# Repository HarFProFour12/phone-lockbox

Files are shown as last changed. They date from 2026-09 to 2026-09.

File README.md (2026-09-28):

# Tamagotchi Style Phone Lockbox

This is my custom phone lockbox that turns putting your phone away into a little game. All you have to do is put your phone inside, choose for how long you want to lock your phone, and let Byte (the tamagotchi character), keep you company while you stay off your phone.

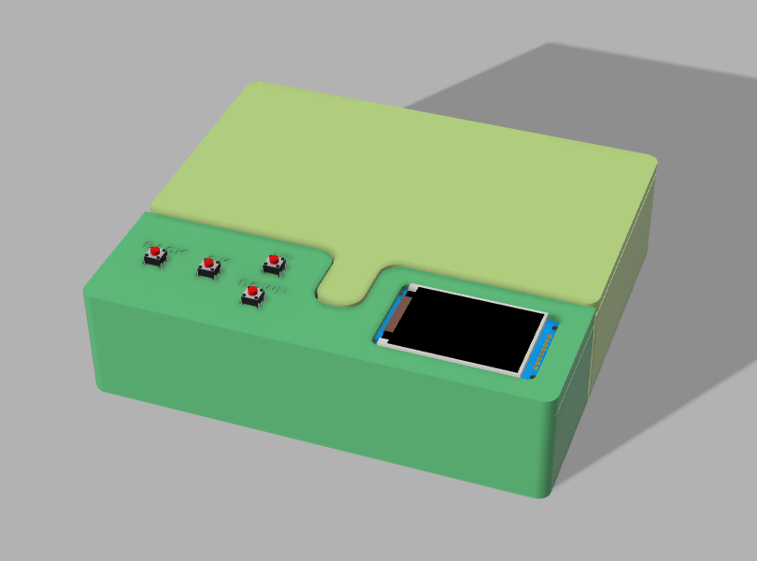
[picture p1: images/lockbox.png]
Phone Lockbox (render)


## Features

* Phone locking for specific amount of time
* Tamagotchi character (Byte)
* Button-controlled UI
* 2" 240×320 SPI TFT IPS screen
* Adjustable lock time
* Adjustable screen brightness
* Battery indicator
* Locking mechanism controlled by solenoid lock

## Interface

The UI is designed with simple menus so it can be navigated using only four buttons (okay, back, up, down). The Home screen uses this layout:

* **Lock Phone**
* **Stats**
* **Settings**
* **About**

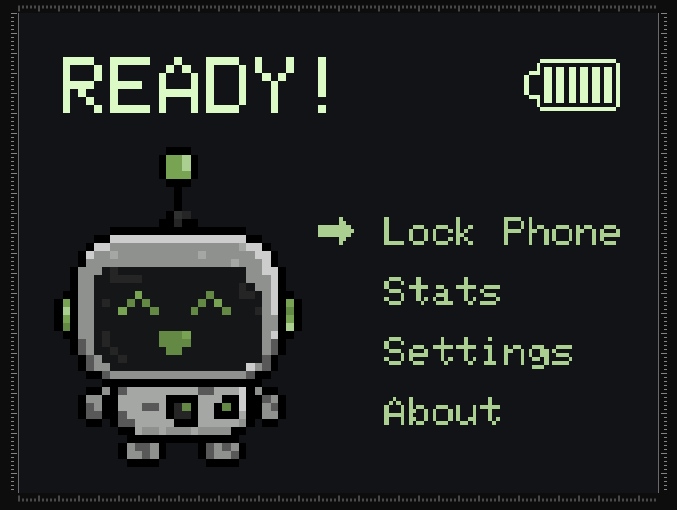
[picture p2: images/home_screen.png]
Home Screen UI


The Settings menu currently contains:

* **Lock Time**
* **Brightness**
* **Sounds**
* **System**

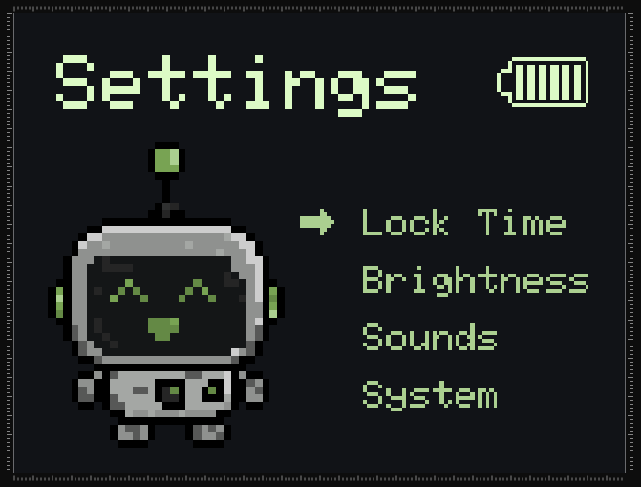
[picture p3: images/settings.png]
Settings Page UI


I've designed seperate sprites for Byte, including idle, happy, celebrating, excited, sad, thinking and sleeping, which change according to your actions.

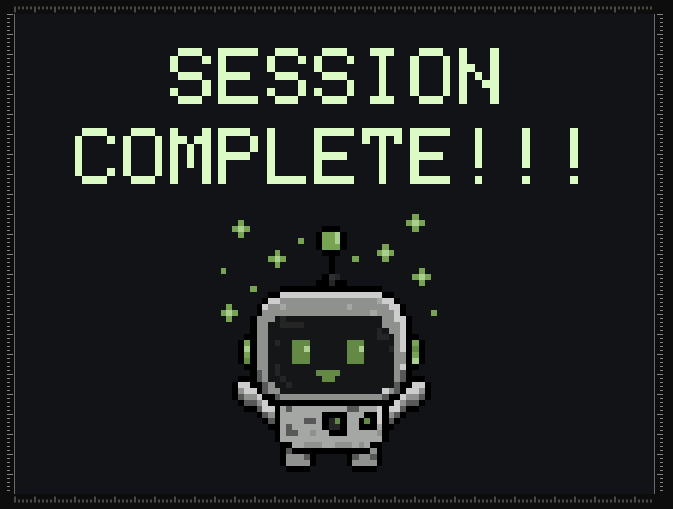
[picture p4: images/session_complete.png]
Session Completed Screen


## How It Works

The lockbox is controlled by an **ESP32-C6-DevKitC-1**. The display show the current screen and whether Byte's happy, sad, excited, etc.. You can control the UI using the 4 physical pushbuttons, which are left from the screen.

When you press "Lock Phone", the lock mechanism starts. First of all, the lipo battrey's current passed through a step=up converter and then activates the solenoid, which unlocks the box. From that time you have 5 seconds to put your phone inside. After that, the solenoid locks, locking yyour phone inside, and Byte's animation changes accordingly.

## Hardware

The current hardware includes the following components:

* ESP32
* Waveshare 2" 240×320 SPI TFT IPS IPS LCD
* 4× pushbuttons
* 12V solenoid lock
* 2000mAh 3.7V LiPo battery
* TP4056 Battery Charging module
* 2x DC-DC boost converter
* 1A 1000V 1N4007 Diode
* Mosfet IRLB8743P N-Channel 150A

## Schematic & Hardware Wiring

The lockbox uses an ESP32-C6 with two parallel step-up converters, which are powered by a 3.7V LiPo cell managed by a TP4056 charging module.

### Power Distribution
* LiPo Battery (3.7V): Connects to TP4056 B+ / B-.
* 3.7V Rail (TP4056 OUT+): Sends input to both boost converters and the voltage divider, which is used to be able to calculate the battery's percentage..
* MT3608 Boost (5V Output): Gives power the ESP32-C6 using the 5V0 pin.
* XL6009 Boost (12V Output): Supplies high voltage to the solenoid lock and also the 1N4007 flyback diode.
* Common Ground (OUT-): All module grounds, MOSFET source, and button rails are connected to the same GND.

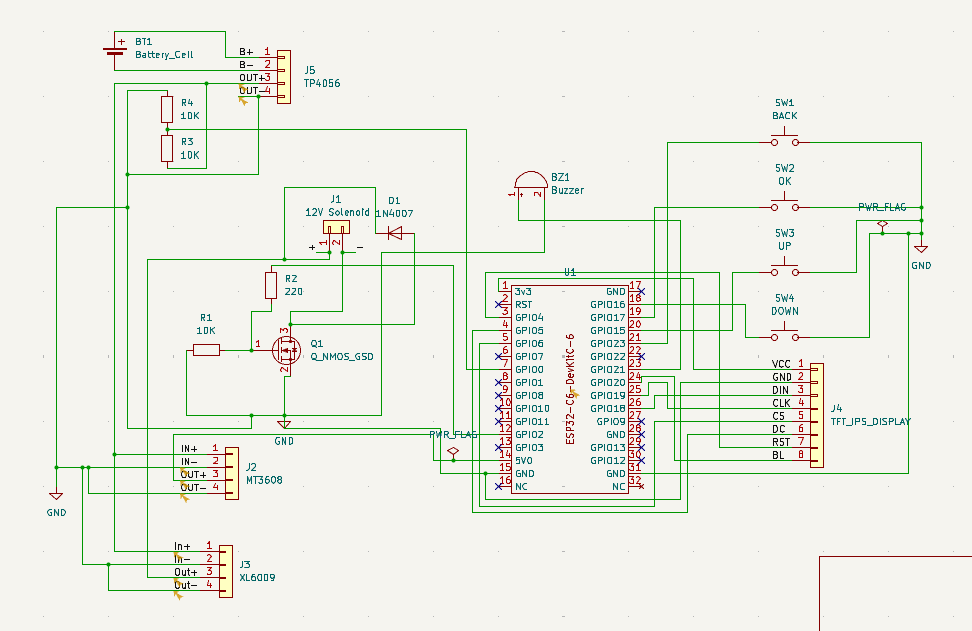
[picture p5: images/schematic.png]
Schematic


## Project Structure

```text
Phone-Lockbox/
├── buttons.cpp
├── buttons.h
├── globals.cpp
├── globals.h
├── graphics.cpp
├── graphics.h
├── hardware.cpp
├── hardware.h
├── home.cpp
├── home.h
├── lock.cpp
├── lock.h
├── main.ino
├── settings.cpp
├── settings.h
├── stats.cpp
├── stats.h
├── ui.cpp
└── ui.h
```
I've split the many screens and functions into different files so it's easier to navigate and can be more easily debugged.

## Current Status

The project is still in the making process.

What I've done so far:

*  Basic TFT IPS interface
*  Home screen
*  Menu navigation
*  Settings screen
*  Lock time adjustment
*  Brightness adjustment
*  Byte animations
*  Solenoid control
*  Actual countdown timer
*  Complete Stats screen
*  Sounds
*  System settings
*  Battery monitoring
*  Complete lock/unlock logic
*  Final enclosure design

I have left to do:

* Getting the parts
* Final hardware assembly

## Design

The lockbox was designed around my **iPhone 13**, with the inside dimensions, and electronics compartment built around it. The box's inside measures to 91.5 mm × 166.7 mm. While phones with about the same dimensions to the iPhone 13 can also fit, it is not guaranteed.

The UI uses pixel-art inspired by tamagotchis.

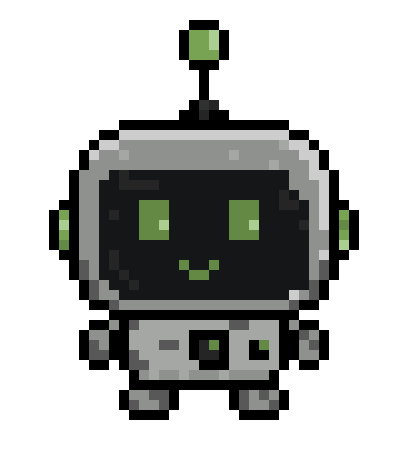
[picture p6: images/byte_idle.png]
Byte


Byte was designed by hand for this project using Piskel (an online tool), with different expressions that match what you do (e.g. put your phone away = happy, completed a session = celebrating, took it out too early = sad, etc.).

## Built With

* Arduino (C++)
* ESP32
* TFT_eSPI (Arduino Library)
* Fusion
* Piskel
* lopaka.app
* 3D printing

## AI Usage

I used AI, mainly for:

- Code debugging: fixing errors and debugging.
- Code structure: help split the code into separate files.
- Byte: generating an first prototype for how Byte would look, which I then recreated and edited myself in Piskel.

The actual project design, assembly, UI, gpraphics, and final code were done by me.

---
### Created for Hack Club’s Stardance.
This project was created as part of Hack Club Stardance, a Hack Club event encouraging young people to build and ship their own projects.

---
**Made by Harry Fanouriakis**

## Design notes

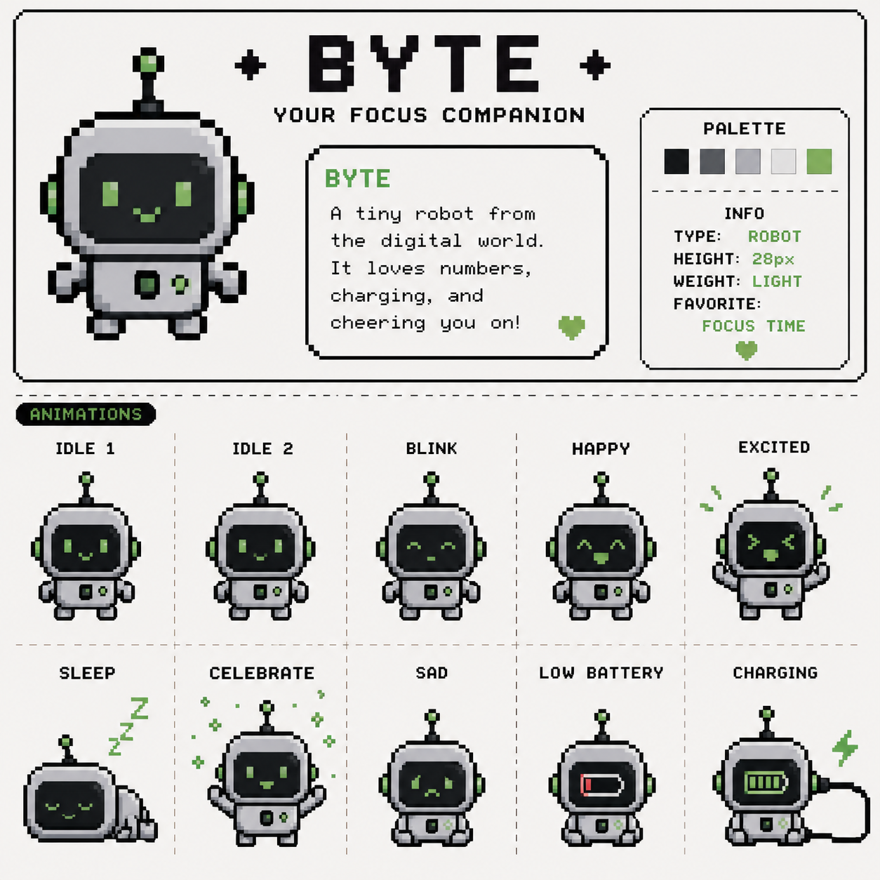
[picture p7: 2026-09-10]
Byte_Sprite/Tamagotchi Lockbox UI Image Jul 27 2026.png

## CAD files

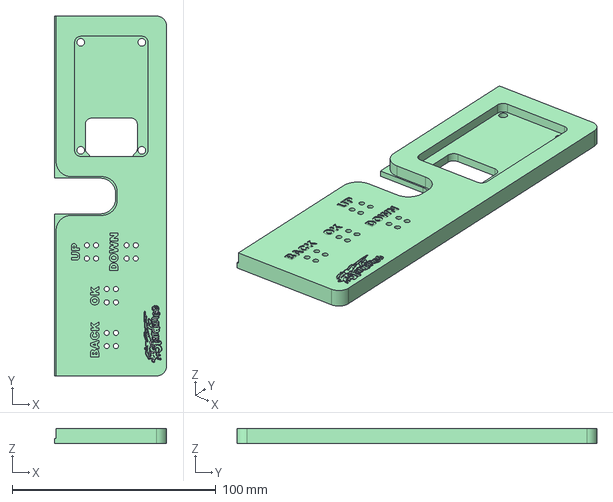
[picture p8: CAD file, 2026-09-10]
3d Files/STEPs/box_assembled.step
55.1 x 176.7 x 7.50 mm

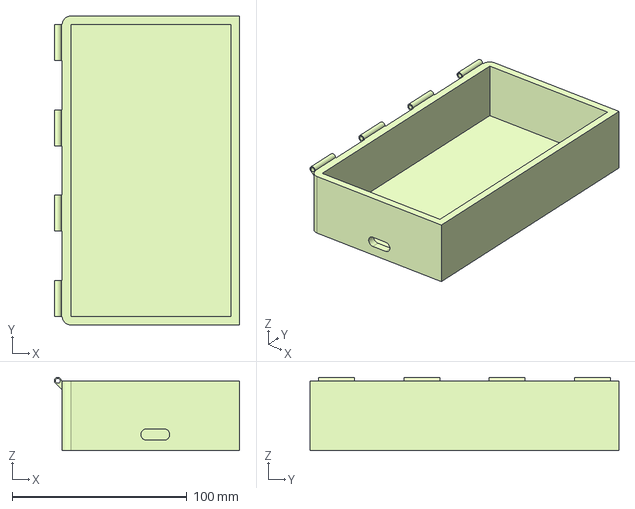
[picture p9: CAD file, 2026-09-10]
3d Files/STEPs/main_body.step
106.0 x 176.7 x 42.0 mm

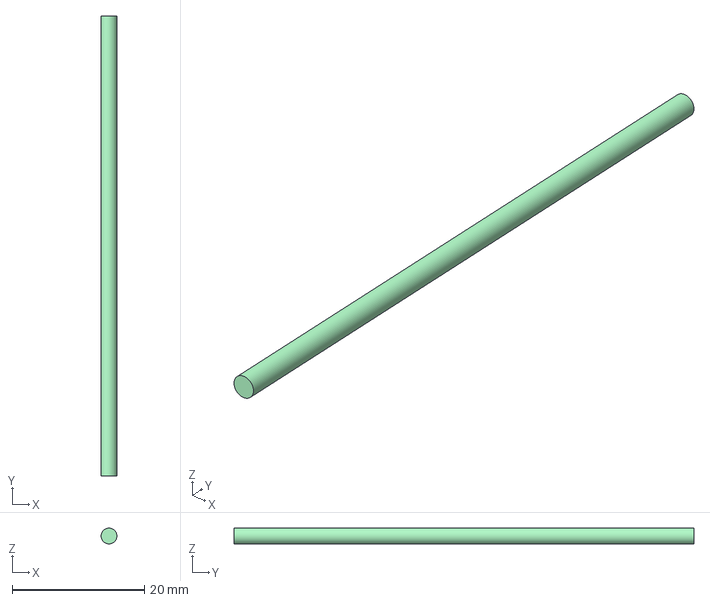
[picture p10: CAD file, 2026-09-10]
3d Files/STEPs/rod2.step
2.40 x 69.5 x 2.40 mm

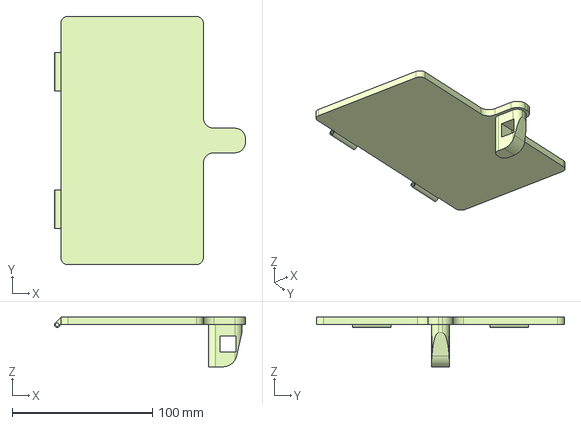
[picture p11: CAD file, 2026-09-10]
3d Files/STEPs/lid.step
136.0 x 176.7 x 35.3 mm

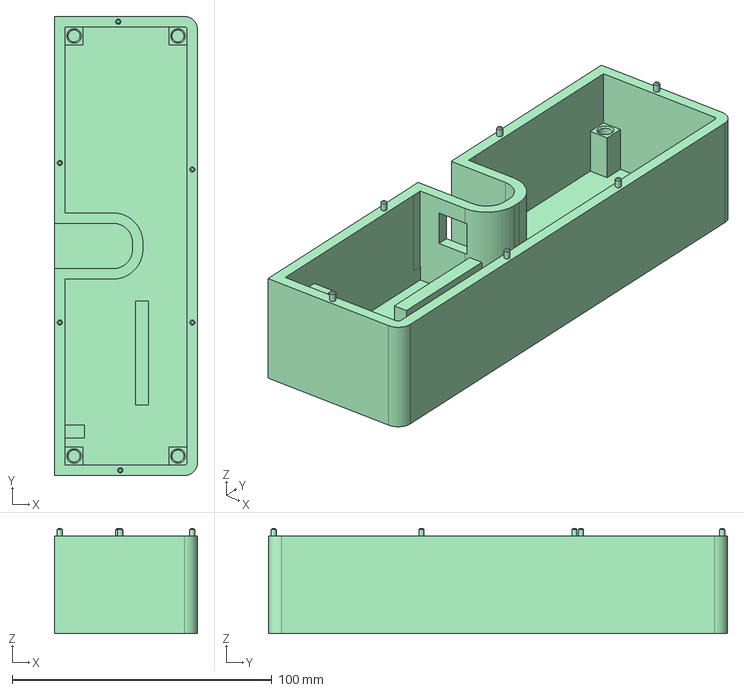
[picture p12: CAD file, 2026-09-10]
3d Files/STEPs/compartment_bottom.step
55.1 x 176.7 x 40.5 mm

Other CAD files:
3d Files/STEPs/compartment_top.step
3d Files/STEPs/rod1.step
3d Files/Autodesk Fusion Archive Files/lockbox_assembled.f3z
3d Files/STLs/compartment_bottom.stl
3d Files/STLs/compartment_top.stl
3d Files/STLs/lid.stl
3d Files/STLs/main_body.stl
3d Files/STLs/rod1.stl
3d Files/STLs/rod2.stl

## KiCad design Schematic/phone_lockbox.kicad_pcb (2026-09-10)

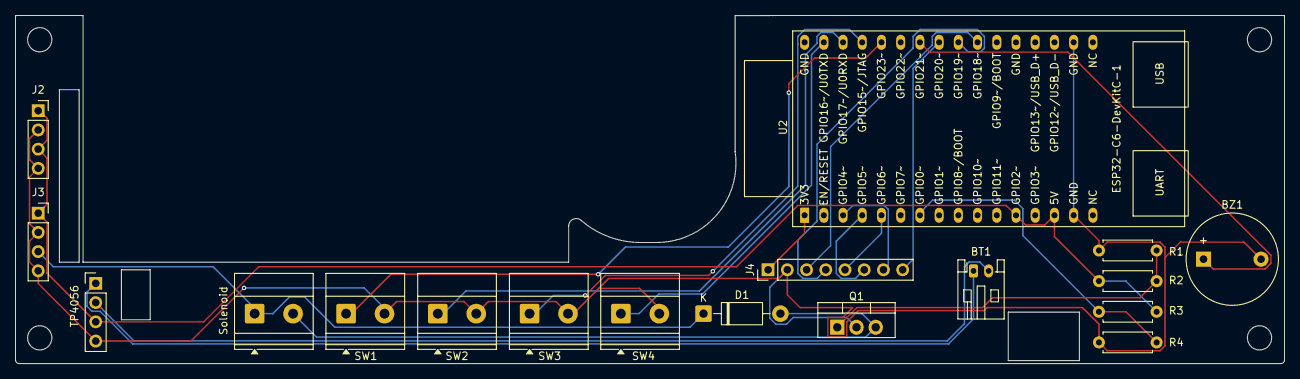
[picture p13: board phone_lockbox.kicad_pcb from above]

Board: 2 copper layers, 167.7 x 46.0 mm, 18 parts (0 on the bottom side), 20 nets.

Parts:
BT1: Battery_Cell; JST_PH_S2B-PH-K_1x02_P2.00mm_Horizontal
BZ1: Buzzer; Buzzer_12x9.5RM7.6
D1: 1N4007; D_DO-41_SOD81_P10.16mm_Horizontal
J2: MT3608; PinSocket_1x04_P2.54mm_Vertical
J3: XL6009; PinSocket_1x04_P2.54mm_Vertical
J4: TFT_IPS_DISPLAY; PinHeader_1x08_P2.54mm_Vertical
Q1: Q_NMOS_GSD; TO-220-3_Vertical
R1, R3, R4: 10K; R_Axial_DIN0207_L6.3mm_D2.5mm_P7.62mm_Horizontal
R2: 220; R_Axial_DIN0207_L6.3mm_D2.5mm_P7.62mm_Horizontal
SW1: BACK; TerminalBlock_Phoenix_MKDS-1,5-2-5.08_1x02_P5.08mm_Horizont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
SW2: OK; TerminalBlock_Phoenix_MKDS-1,5-2-5.08_1x02_P5.08mm_Horizont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
SW3: UP; TerminalBlock_Phoenix_MKDS-1,5-2-5.08_1x02_P5.08mm_Horizont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
SW4: DOWN; TerminalBlock_Phoenix_MKDS-1,5-2-5.08_1x02_P5.08mm_Horizont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
Solenoid: 12V Solenoid; TerminalBlock_Phoenix_MKDS-1,5-2-5.08_1x02_P5.08mm_Horizont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
TP4056: TP4056; PinHeader_1x04_P2.54mm_Vertical
U2: ESP32-C6-DevKitC-1

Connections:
/+: D1.1 (K), J3.3, Solenoid.1
/-: D1.2 (A), Q1.3 (D), Solenoid.2
/B+: BT1.1 (+), TP4056.1
/B-: BT1.2 (-), TP4056.2
/BL: J4.8, U2.25 (GPIO20)
/CLK: J4.4, U2.24 (GPIO19)
/CS: J4.5, U2.5 (GPIO6)
/DC: J4.6, U2.4 (GPIO5/MTDI)
/DIN: J4.3, U2.23 (GPIO18)
/IN+: J2.1, J2.3, J3.1, R2.1, R3.2, TP4056.3, U2.12 (GPIO2), U2.14 (5V)
/RST: J4.7, U2.3 (GPIO4/MTMS)
/VCC: J4.1, U2.1 (3V3)
GND: BZ1.2 (-), J2.2, J2.4, J3.2, J3.4, J4.2, Q1.2 (S), R1.1, R4.1, SW1.2, SW2.2, SW3.2, SW4.2, TP4056.4, U2.15 (GND), U2.18 (GND)
unnamed: BZ1.1 (+), U2.26 (GPIO21)
unnamed: Q1.1 (G), R1.2, R2.2
unnamed: R3.1, R4.2, U2.7 (GPIO0)
unnamed: SW3.1, U2.29 (GPIO15/JTAG)
unnamed: SW4.1, U2.31 (GPIO16/U0TXD)
unnamed: SW2.1, U2.30 (GPIO17/U0RXD)
unnamed: SW1.1, U2.28 (GPIO23)

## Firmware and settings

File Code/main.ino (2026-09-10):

#include "globals.h"
#include "hardware.h"
#include "buttons.h"
#include "lock.h"
#include "home.h"

void setup() {
  Serial.begin(115200);
  delay(500);
  Serial.println("Booting...");

  loadSettings();
  Serial.println("Settings loaded");

  initDisplay();
  Serial.println("Display initialized");

  initPins();
  Serial.println("Pins initialized");

  lastActivityMs = millis();
  updateBrightness();
  Serial.println("Brightness set");

  if (phone_locked) {
    Serial.println("Drawing locked screen");
    drawLocked();
  } else {
    Serial.println("Drawing home screen");
    drawHome();
  }

  Serial.println("Setup complete");
}

void loop() {
  checkIdleSleep();
  updateBrightness();
  updateLock();
  handleButtons();
}

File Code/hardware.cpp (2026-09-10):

#include "hardware.h"
#include "globals.h"

void initDisplay() {
  tft.init();
  tft.setRotation(1);
}

void initPins() {
  pinMode(upPin, INPUT_PULLUP);
  pinMode(downPin, INPUT_PULLUP);
  pinMode(okPin, INPUT_PULLUP);
  pinMode(backPin, INPUT_PULLUP);

  pinMode(solenoidPin, OUTPUT);
  digitalWrite(solenoidPin, LOW);

  pinMode(buzzerPin, OUTPUT);
  noTone(buzzerPin);

  pinMode(batteryPin, INPUT);

  ledcAttach(backlightPin, 5000, 8);
}

void pulseSolenoid() {
  digitalWrite(solenoidPin, HIGH);
  delay(7500);
  digitalWrite(solenoidPin, LOW);
}

void updateBrightness() {
  if (screenAsleep) {
    return;
  }
  int pwm = map(brightness, 0, 100, 0, 255);
  ledcWrite(backlightPin, pwm);
}

void updateBattery() {
  int raw = analogRead(batteryPin);
  float voltage = (raw / 4095.0) * 3.3 * 2.0;

  int percentage = map(voltage * 100, 300, 420, 0, 100);
  percentage = constrain(percentage, 0, 100);
  batteryPercent = percentage;
}

static void beep(unsigned int freq, unsigned int durationMs) {
  if (!soundsOn) {
    return;
  }
  tone(buzzerPin, freq, durationMs);
}

void beepClick() {
  beep(1200, 40);
}

void beepConfirm() {
  beep(1800, 80);
}

void beepLockStart() {
  beep(880, 120);
  delay(130);
  beep(1320, 160);
}

void beepUnlock() {
  beep(1320, 100);
  delay(110);
  beep(1760, 100);
  delay(110);
  beep(2200, 160);
}

void beepCancel() {
  beep(600, 150);
  delay(160);
  beep(400, 220);
}

void sleepScreen() {
  screenAsleep = true;
  ledcWrite(backlightPin, 0);
}

void wakeScreen() {
  screenAsleep = false;
  updateBrightness();
}

void checkIdleSleep() {
  if (!screenAsleep && millis() - lastActivityMs >= idleTimeoutMs) {
    sleepScreen();
  }
}
